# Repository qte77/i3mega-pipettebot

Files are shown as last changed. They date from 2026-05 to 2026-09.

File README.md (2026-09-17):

# i3mega-pipettebot

> Turn a cheap consumer 3D printer into a sub-$150 disposable-tip pipetting
> robot driven by a **DLAB dPette** electronic pipette and Python.

Reference build is **dpette+i3** (Anycubic i3 Mega + DLAB dPette+);
**Geeetech A30 (Smartto firmware)** is also a supported gantry via the
same `pipettebot` library — discovery picks the firmware family from
`M115` and the `safe_home` dispatcher routes Marlin → plain `G28` and
Smartto → polled-Z descent (firmware `G28 Z` is broken on stock A30
builds; see [ADR 0004](docs/adr/0004-printer-firmware-policy-and-safe-home.md)
and the [bring-up notes](docs/research/gantry-firmware-alternatives.md)).
Firmware stays unmodified on every supported platform; the print head
and PCB are physically removed from the carriage and the chassis is
repurposed as a 3-axis motion platform with the dPette mounted on the
bare carriage (see [`docs/3d-parts.md`](docs/3d-parts.md)). The pipette
is driven over a separate USB-serial link via
[`dpette-usb-driver`](https://github.com/Lambda-Biolab/dpette-usb-driver),
and used-tips bin pickup is delegated to an optional companion SO-101
arm via [`so101-biolab-automation`](https://github.com/qte77/so101-biolab-automation).
The library is also pipette-agnostic via the `_Pipette` Protocol.

**Write-up:** [A $150 Pipetting Robot from a Stock 3D Printer](https://qte77.github.io/pipettebot-sub-150-pipetting-robot/) — the full build story. This gantry is also the *motion layer* of a larger [self-driving-lab agent loop](https://qte77.github.io/open-self-driving-lab-agent-loop/).

<details>
<summary>dpette+i3 in action (animated GIF)</summary>
<p align="center">
  dpette+i3 (i3 Mega) pipetting robot in action
</p>
</details>








## Why this matters

A pipetting robot you can build for the price of a 3D printer, with a
disposable-tip workflow and Python control. See
[docs/UserStory.md](docs/UserStory.md) for the target personas,
end-to-end workflows, and what is explicitly out of scope.

| Solution | Cost | Tips | API control |
|---|---|---|---|
| **i3 Mega (used) + dPette (new) + this repo** | **~$150** | Disposable  | Python |
| **A30 (used) + dPette (new) + this repo** | **~$200** | Disposable  | Python |
| [Science Jubilee][sj] + OT-2 pipette | ~$900+ build  | Disposable  | Python |
| [Opentrons OT-2][ot2] | from $15,950  | Disposable  | Python |

[sj]: https://science-jubilee.readthedocs.io/en/latest/
[ot2]: https://opentrons.com/products/ot-2-robot

Prices: Opentrons is the vendor list; Jubilee is a community build estimate
anchored at the [Science Jubilee project][sj] ([OT-2 pipette toolhead][sj-pipette]).

[sj-pipette]: https://science-jubilee.readthedocs.io/en/latest/building/pipette_tool.html

## Quickstart

Requires [`uv`](https://docs.astral.sh/uv/).

```bash
# Install uv once (if you don't have it):
# curl -LsSf https://astral.sh/uv/install.sh | sh

git clone https://github.com/qte77/i3mega-pipettebot.git
cd i3mega-pipettebot
make setup_dev
make test
```

`make setup_dev` runs `uv sync --extra dev`; `make test` runs the
mocked-serial test suite (no hardware required). `make help` lists every
recipe grouped by section.

## Run the demo (requires hardware)

Two separate guides cover the physical/electrical setup and the
well-origin calibration before you run the demo:

- [`docs/hardware.md`](docs/hardware.md) — cabling, port discovery (CH340 vs CP2102), Marlin firmware sanity check
- [`docs/calibration.md`](docs/calibration.md) — finding well A1 with `M114`, the 9 mm pitch check, where to set the constants

After hookup, sanity-check ports + firmware **before any motion**:

```bash
uv run tools/preflight.py
```

This reads `M115` from Marlin and the EEPROM packet from the dPette;
no motion is sent. Preflight passes when **either** device is found —
the gantry and the pipette are exercised independently.

To chain discovery directly into the next command, use `--export`:

```bash
eval "$(uv run python tools/preflight.py --export)" \
  && uv run python examples/showcase_v0_i3_pipette_sim.py
```

Then the demo. Hardware examples drive the gantry (and, for the
canonical end-to-end demo, also the dPette) and tee the Marlin stream
to disk for replay/SD use. **Precondition for all full-plate demos:
REMOVE TIPS from the dPette before running.** Phase 1 issues
`G28 X Y Z` — Z homes to its calibrated tip-on-deck zero, which would
drag any mounted tip into the deck.

```bash
# back-well ↔ front-well pipetting cycle (older two-well demo, simulated)
uv run examples/showcase_v0_i3_pipette_sim.py

# Full 96-well plate fill, gantry-only (aspirate/dispense simulated via
# Z dives). Useful for gantry/cabling bring-up without the dPette.
uv run examples/showcase_v0_i3_full_plate.py

# Canonical end-to-end demo — same gantry tour with REAL dPette
# aspirate/dispense (B3 SUCK at reservoir, B3 BLOW at each SBS column).
# Needs both PRINTER_PORT and PIPETTE_PORT set.
uv run examples/showcase_v0_i3_full_pipettebot.py

# dPette-only bench test — 12 aspirate/dispense cycles, no gantry. Use
# to measure real B3 motor timing. Run with tip in air or over waste.
uv run examples/showcase_v0_i3_full_dpette_cycles.py

# Every showcase (column/dpette-cycles/rows) accepts a TOML experiment
# profile via PIPETTE_PROFILE — drives the cycle count, per-cycle volumes,
# and any pre-mixed reservoir gradient notes. Profile length overrides the
# script's default (NUM_COLUMNS / NUM_CYCLES). See
# `examples/experiment_profiles/` for samples
# (calibration_curve_demo.toml, gradient_reservoir_demo.toml).
PIPETTE_PROFILE=examples/experiment_profiles/calibration_curve_demo.toml \
  uv run examples/showcase_v0_i3_full_dpette_cycles.py
PIPETTE_PORT=/dev/ttyUSB1 \
  PIPETTE_PROFILE=examples/experiment_profiles/calibration_curve_demo.toml \
  uv run examples/showcase_v0_i3_full_pipettebot_rows.py

# Every gantry-using example also accepts MOTION_PROFILE to dial gantry
# accel/jerk between slow / mid / fast (or off to skip the install).
# Default is mid (liquid-handling friendly). See
# `src/pipettebot/motion_profile.py` for the bundled values + semantics.
MOTION_PROFILE=fast NUM_CYCLES=1 \
  uv run examples/showcase_v0_i3_full_pipettebot_rows.py

# Home — full `G28` to (X=0, Y=0, Z=0). Bootstrap installs the same
# liquid-handling motion profile (M203/M201/M204/M205) that every
# showcase_v0_*.py installs, so chaining a home before a tour leaves a
# known motion state. No partial-axis shortcuts.
uv run examples/home_G28_fast_i3.py
```

### Geeetech A30 (Smartto firmware)

The same toolchain drives an A30 — discovery picks `smartto` from `M115`,
the `safe_home` library routes around firmware-broken `G28 Z` via a
polled-Z descent against the working inductive sensor, and a parallel
showcase exercises the deck:

```bash
# Z home only — polled descent finds the sensor, declares G92 Z0.
uv run examples/home_safe_a30.py

# End-to-end liquid-handling demo — discovery, home, N cycles with
# split-feedrate dives, post-cycle re-home, park at (0, 0, 0). Runs
# in GANTRY-ONLY mode when PIPETTE_PORT is unset (motion executes for
# real; aspirate/dispense are log-only stubs).
uv run examples/showcase_v0_a30_liquid_handling.py
```

See [`docs/research/gantry-firmware-alternatives.md`](docs/research/gantry-firmware-alternatives.md)
for the A30 bring-up notes and [ADR 0004](docs/adr/0004-printer-firmware-policy-and-safe-home.md)
for the `safe_home` design.

The full-plate tour's deck layout (slot positions, motion constants,
tour sequence) is the canonical spec — see
[`docs/deck-layout.md`](docs/deck-layout.md).

### Hardware diagnostics (`tools/`)

For headless-gantry bring-up, debugging, and post-removal sanity checks:

| Tool | Purpose |
|---|---|
| `tools/preflight.py` | Port discovery + Marlin/dPette firmware probe. |
| `tools/diagnose_axis.py` | Per-axis (`AXIS=X\|Y\|Z`) stepped motion under operator confirmation. Reports `M119` first, never homes. |
| `tools/marlin_repl.py` | Interactive G-code REPL with built-in command cheat-sheet (`?`). For ad-hoc `M119`, `M999`, `M114`, `M503`, etc. |

See [`docs/marlin-commands.md`](docs/marlin-commands.md) for the full
G/M-code reference and i3 Mega coordinate orientation.

### CAD + slicer pipeline (`tools/cad/`, `tools/slicer/`)

build123d CAD scripts for printable parts — tip rack, plate holder, dPette
cradles, tip ejector, **i3 carriage dPette+ mount**. `make render_parts`
generates STL+SVG from `tools/cad/parts.json`; `make check_prints` slices
via OrcaSlicer (preferred) or PrusaSlicer (fallback). Hardware measurements
are consolidated in `tools/cad/measurements.py`. See
[`docs/3d-parts.md`](docs/3d-parts.md) for the CAD pipeline design
rationale and payload / Z-envelope math.

Expected behavior: home → bed sweeps to back well → 5 cm Z plunger
stroke → bed sweeps to front well → another stroke → home.

## Architecture

```text
examples/showcase_v0_i3_pipette_sim.py     examples/showcase_v0_a30_liquid_handling.py
        │                                                │
        ▼                                                ▼
raw serial @ 250000 baud                   pipettebot.gantry + safe_home dispatcher
        │                                                │
        ▼                                                ▼
/dev/ttyUSB*  (Marlin / AI3M)              /dev/ttyUSB*  (Smartto / A30 @ 115200)
        │
        └─ tee G-code stream ──► OUTPUT_GCODE file (replay / SD)
```

Both printer families share `tools/preflight.py --export` for discovery
(`PRINTER_PORT` is the single env var) and the same library. Firmware
family is identified by `pipettebot.devices.discover()`, and
`safe_home` dispatches per-family: plain `G28` on Marlin, polled-Z
descent on Smartto/A30 (firmware `G28 Z` is broken on stock Smartto).
See [ADR 0004](docs/adr/0004-printer-firmware-policy-and-safe-home.md).

The dPette is wired in via `dpette.DPetteDriver`.
`showcase_v0_i3_full_pipettebot.py` runs the full plate fill end-to-end —
gantry transit + real B3 SUCK/BLOW at the bottom of each dive.
`showcase_v0_i3_full_plate.py` keeps the gantry-only path (plunger
simulated via Z) for bring-up without the pipette.
`showcase_v0_a30_liquid_handling.py` is the A30 counterpart with the
polled-Z home + split-feedrate dives; runs in gantry-only mode when
`PIPETTE_PORT` is unset.

Seven library modules under `src/pipettebot/`: `gantry.py` (G-code
wrapper + `send`/`query`/`flush_input` public surface), `bot.py`
(`PipetteBot` composer), `devices.py` (firmware discovery via M115,
per-family `FirmwarePolicy`, `safe_home` dispatcher),
`experiment_profile.py` (TOML experiment-profile loader; see
[`examples/experiment_profiles/`](examples/experiment_profiles/)),
`motion_profile.py` (bundled SLOW/MID/FAST gantry-tuning factors at
3x ratio; `MOTION_PROFILE` env selects), `cli_profile.py` (shared
`PIPETTE_PROFILE` / `PIPETTE_VOLUME_UL` env resolution), and
`__init__.py` (re-exports). No deck library, no safety limits, no
calibration yet — the caller passes raw `(x, y, z)`.

## Development

| Recipe | What it runs |
|---|---|
| `make setup_uv` | install uv (idempotent — skips if already on PATH) |
| `make setup_prod` | `uv sync` (runtime deps only — pyserial + dpette) |
| `make setup_dev` | `uv sync --extra dev` (runtime + ruff/mypy/pytest/complexipy/hypothesis) |
| `make setup_cad` | `uv sync --extra cad` (build123d) |
| `make setup_slicer` | probe for OrcaSlicer (preferred) or PrusaSlicer (fallback) |
| `make setup_prusa_presets` | extract MK4 Input Shaper presets into `~/.config/PrusaSlicer/` (enables `make slice` to reference them by name) |
| `make setup_all` | `setup_dev` + `setup_cad` + best-effort slicer/diagramforge |
| `make validate` | `ruff format --check` + `ruff check` + `mypy --strict` + `pytest -m "not hardware"` |
| `make quick_validate` | `ruff check` + `mypy` only (no tests) |
| `make lint` | `ruff check` + `mypy --strict` |
| `make lint_fix` | `ruff format` + `ruff check --fix` |
| `make test` | `pytest -v` (hardware tests excluded via `pyproject.toml`) |
| `make test_bats` | bats tests for Makefile recipe wiring (`tests/bats/*.bats`) |
| `make check_complexity` | `complexipy src/pipettebot/` (max 15) |
| `make check_links` | `lychee` against the repo (config in `.lychee.toml`) |
| `make check_docs` | `markdownlint-cli2 "**/*.md"` |
| `make check_deploy` | shellcheck + bats + `systemd-analyze verify` for `tools/deploy/` (best-effort `udevadm`) |
| `make render_parts` | build123d → STL/STEP/SVG (driven by `tools/cad/parts.json`) |
| `make check_prints` | headless slice via `tools/slicer/validate.py --all` |
| `make render_all` | `render_parts` + `check_prints` (full CAD-to-slicer gate) |
| `make slice PART=<name>` | PrusaSlicer STL → tracked `hardware/bgcode/<area>/<part>.bgcode` via named Input Shaper presets (run `setup_prusa_presets` first) |
| `make dev_diagram` | run diagramforge's dev server for architecture-diagram editing (run `setup_diagramforge` first) |

Recipes prefer the local `.venv/bin/<tool>` binary if installed, else fall
back to `uv run`. On read-only hosts where `uv run` can't write to
`~/.cache/uv`, run `make setup_dev` first (which materialises the venv)
or set `UV_CACHE_DIR=$TMPDIR/uv-cache`.

The `setup_*` recipes pass `--inexact` to `uv sync` so they are
**additive**: running `setup_dev` after `setup_cad` keeps `build123d`
installed (and vice versa). Without `--inexact`, `uv sync` is exact
and uninstalls anything outside the requested extras.

Hardware tests are gated by `@pytest.mark.hardware`:

```bash
uv run pytest -m hardware
```

## Architecture decision: why PC-as-host (no firmware mods)

Marlin runs unmodified. Pipetting cycles are slow (seconds per move,
seconds per aspirate); USB-serial round-trip latency (~20–50 ms) is
inconsequential. Firmware integration (Stage 1 config patch, Stage 2
UART tap to dPette) is deliberately **out of scope** for the current
PC-as-host architecture. See [ADR 0005](docs/adr/0005-pc-as-host.md)
for the full Stage 0–2c breakdown and what would trigger moving past
Stage 0.

## Related repositories

- [Lambda-Biolab/dpette-usb-driver](https://github.com/Lambda-Biolab/dpette-usb-driver) — pipette serial driver (imported as `dpette`); reference pipette for the **dpette+i3** build.
- [qte77/so101-biolab-automation](https://github.com/qte77/so101-biolab-automation) — dual SO-101 arm controller; optional companion that retrieves the used-tips bin after the i3 homes (issue #120).
- [xg590/Learn_dPettePlus](https://github.com/xg590/Learn_dPettePlus) — original reverse-engineering of the dPette+ serial protocol (source of the official Chinese protocol document); intellectual lineage for `dpette-usb-driver`.

## Documentation

- [docs/UserStory.md](docs/UserStory.md) — user personas, target workflows, scope and acceptance criteria
- [docs/roadmap.md](docs/roadmap.md) — forward-looking work (near-term, Stage 1+ firmware, deferred API tiers, anti-roadmap)
- [docs/hardware.md](docs/hardware.md) — i3 Mega + dPette wiring, port discovery, firmware sanity check, dPette+ specs
- [docs/calibration.md](docs/calibration.md) — well-A1 origin procedure, 9 mm pitch check
- [docs/deck-layout.md](docs/deck-layout.md) — deck slot extents, motion constants, four-phase tour sequence (canonical spec for `showcase_v0_i3_full_plate.py`)
- [docs/marlin-commands.md](docs/marlin-commands.md) — Marlin G/M-code reference + i3 Mega coordinate orientation
- [docs/3d-parts.md](docs/3d-parts.md) — CAD pipeline design rationale, payload + Z envelope math, SBS labware reference
- [docs/sbc-deployment.md](docs/sbc-deployment.md) — Path 2 (Single-Board Computer on-printer) deployment
- [docs/research/gantry-firmware-alternatives.md](docs/research/gantry-firmware-alternatives.md) — A30 / Smartto bring-up notes (firmware-broken `G28 Z`, polled-Z descent recipe)
- [docs/research/aspirate-monitoring.md](docs/research/aspirate-monitoring.md) — aspirate verification technologies (Hamilton MAD / TADM survey, dPette+ reuse verdict)
- [docs/research/tip-disposal-belt-module.md](docs/research/tip-disposal-belt-module.md) — used-tip disposal mechanisms (conveyor-belt printer landscape, standalone belt module BOM)
- [docs/research/alternative-pipettes.md](docs/research/alternative-pipettes.md) — candidate pipettes for the `_Pipette` Protocol (dPette+ reference, multichannel, Opentrons GEN2, ac-rad Digital Pipette)
- [docs/adr/](docs/adr/) — architectural decision records
- [AGENTS.md](AGENTS.md) — agent rules, decision framework, architecture
- [AGENT_LEARNINGS.md](AGENT_LEARNINGS.md) — gotchas as we discover them
- [CONTRIBUTING.md](CONTRIBUTING.md) — dev workflow
- [CHANGELOG.md](CHANGELOG.md) — version history

## License

Apache-2.0 — see [LICENSE](LICENSE) and [NOTICE](NOTICE).

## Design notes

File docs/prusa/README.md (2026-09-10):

---
title: "Prusa MK4 + PrusaSlicer workflow notes"
status: "ACTIVE"
updated: "2026-05-17"
---

Workflow notes and CLI quirks discovered while slicing this repo's
labware (deck plate + dpette parts) on a Prusa MK4 with PrusaSlicer
2.9.4. Recommended path for actual prints is the **GUI**, not the
CLI — see "When to use the CLI" below.

## Quick reference

| What | Where |
|---|---|
| Bed dimensions (MK4) | 250 mm (X) × 220 mm (Y) × 220 mm (Z) |
| System preset bundle | `/usr/share/PrusaSlicer/profiles/PrusaResearch.ini` (1.5 MB, 36 MK4 variants) |
| User config dir | `~/.config/PrusaSlicer/` (presets dirs empty by default — GUI reads system bundle) |
| Repo profiles | `tools/slicer/profiles/*.ini` (minimal; documentation + reference only) |
| Repo STL output | `hardware/stl/<area>/<part>.stl` |
| Repo STEP output | `hardware/step/<area>/<part>.step` |
| Network upload to MK4 | PrusaLink HTTP over RJ45 (`tools/slicer/upload_to_prusalink.py`) |
| Offline upload to MK4 | USB-A thumb drive on the printer front |
| Binary G-code (`.bgcode`) | Smaller, MK4 native — use `--binary-gcode` |

## PrusaSlicer 2.9.4 CLI quirks (verified)

These bit us during this work — document so future-us doesn't
re-debug. Tested with `prusa-slicer 2.9.4 (Fedora build)`.

### Quirk 1 — `.ini` profiles don't reliably load via `--load`

The minimal profiles under `tools/slicer/profiles/*.ini` set keys
like `bed_shape`, `binary_gcode`, `gcode_flavor`, `thumbnails`,
`layer_height`, `fill_density`, `temperature`, and the per-feature
speed keys (`perimeter_speed`, `infill_speed`, ...).

**Behavior**: when invoked as `prusa-slicer --load profile.ini …`,
PrusaSlicer silently falls back to **defaults** for most of these
keys. The slicer doesn't error or warn; the output just doesn't
match the profile.

**Confirmed-loaded** via `--load`:

- `nozzle_diameter` (sometimes)
- `printer_model` (sometimes)
- A few filament keys

**Confirmed-NOT-loaded** via `--load`:

- `bed_shape` — falls back to 200 × 200 default
- `binary_gcode` — output stays plain ASCII G-code
- `gcode_flavor` — no MK4 hints in output
- `thumbnails` — no thumbnails block, no preview on MK4 screen
- `layer_height`, `fill_density`, `brim_width` — default values used
- All `*_speed` keys — defaults used (60 / 80 / 130 mm/s)
- `temperature` (filament) — defaults used

**Workaround**: pass every required key as an **explicit CLI flag**.
A working ultra-draft invocation:

```bash
prusa-slicer --binary-gcode --export-gcode \
  --bed-shape 0x0,250x0,250x220,0x220 \
  --gcode-flavor marlinfirmware \
  --thumbnails 220x124/PNG,16x16/PNG \
  --printer-model MK4 \
  --nozzle-diameter 0.4 \
  --layer-height 0.3 --first-layer-height 0.2 \
  --perimeters 2 --fill-density 10% \
  --brim-width 5 \
  --temperature 230 --bed-temperature 55 \
  --filament-type PLA --extrusion-multiplier 0.7 \
  --output OUT.bgcode INPUT.stl
```

### Quirk 2 — preset-by-name (`--printer-profile NAME`) fails

The system preset bundle at
`/usr/share/PrusaSlicer/profiles/PrusaResearch.ini` contains 36 MK4
variants (`Original Prusa MK4 0.4 nozzle`, `… Input Shaper 0.4 nozzle`,
etc.) and hundreds of print/filament presets, but the CLI doesn't
find them by name:

```bash
prusa-slicer --printer-profile "Original Prusa MK4 Input Shaper 0.4 nozzle" \
  --print-profile "0.20mm SPEED @MK4IS 0.4" \
  --material-profile "Prusa PLA" …
# Error: Printer profile '…' wasn't found.
```

Pointing at the system bundle with `--datadir
/usr/share/PrusaSlicer` also fails:

```text
Error: Configuration wasn't found. Check your 'datadir' value.
```

`--datadir` expects a USER data dir shape (`print/`, `printer/`,
`filament/` subdirs containing individual preset `.ini` files), not
the system vendor bundle.

**Workaround**: open the file in the GUI once, save the relevant
preset to the user data dir, then `--datadir ~/.config/PrusaSlicer`
will find it. Or just stick with explicit CLI flags.

### Quirk 3 — "objects outside print volume" exits 0

If the input STL's bounding box extends past the bed, PrusaSlicer
prints `All objects are outside of the print volume.` to stdout and
**exits with code 0**. No G-code is written. `make check_prints` /
`tools/slicer/validate.py` doesn't catch this because the gate
keys on exit code + a hand-picked overhang keyword list.

**Workaround**: pre-translate STLs so `min_xy >= 0` before slicing.
We do this for the deck-plate assembly STL (origin at well-plate
left-front means literal coords go negative). A small build123d
helper:

```python
from build123d import Pos, import_stl, export_stl
mesh = import_stl('hardware/stl/labware/deck_plate_assembly.stl')
shifted = Pos(10, -12.5, 0) * mesh   # move bbox min to (0,0,0)
export_stl(shifted, '/tmp/deck_assembly_for_print.stl')
```

**Pending validate.py fix**: add `"outside of the print volume"`
and `"could not be sliced"` to `OVERHANG_KEYWORDS`, and require an
output file to exist before declaring PASS.

### Quirk 4 — `--center` / `--align-xy` don't reposition reliably

The CLI exposes `--center X,Y` and `--align-xy X,Y` transform
options, but in 2.9.4 they did NOT reposition off-bed STLs to fit
in our tests. Pre-translation (Quirk 3) is the only reliable path.

### Quirk 5 — Input Shaper preset must be in user data dir

The MK4 firmware refuses bgcode that wasn't sliced for Input Shaper
("gcode not sliced for input shaping"). The IS-aware preset
`Original Prusa MK4 Input Shaper 0.4 nozzle` lives in the system
bundle at `/usr/share/PrusaSlicer/profiles/PrusaResearch.ini`, but
neither `--printer-profile NAME` nor `--load <bundle>` can select
it directly from there.

The CLI only finds presets in `~/.config/PrusaSlicer/{printer,print,
filament}/`. PrusaSlicer GUI populates this on first run; the CLI
does not.

**Workaround**: extract the resolved preset (walking the `inherits =
*commonMK4*` chain) and write it as a flat `.ini` to the user data
dir. After that, `--printer-profile "Original Prusa MK4 Input
Shaper 0.4 nozzle"` works and emits the correct M593 + IS-tuned
machine_max_acceleration_* / feedrate / jerk values.

Minimal Python extractor:

```python
import re
from pathlib import Path
BUNDLE = '/usr/share/PrusaSlicer/profiles/PrusaResearch.ini'
USER = Path.home() / '.config' / 'PrusaSlicer'

def parse(p):
    sec, name, buf = {}, None, []
    for line in open(p):
        m = re.match(r'^\[([^\]]+)\]\s*$', line)
        if m:
            if name: sec[name] = buf
            name, buf = m.group(1), []
        else: buf.append(line)
    if name: sec[name] = buf
    return sec

def kv(lines):
    d = {}
    for ln in lines:
        s = ln.strip()
        if s and not s.startswith('#') and '=' in s:
            k, v = s.split('=', 1); d[k.strip()] = v.strip()
    return d

def resolve(sec, full, visited=None):
    visited = visited or set()
    if full in visited: return {}
    visited.add(full)
    body = kv(sec[full])
    inh = body.pop('inherits', None)
    if inh:
        kind = full.split(':',1)[0]
        for parent in re.split(r'[;,]', inh):
            p = parent.strip().strip('"\'')
            if p:
                for k, v in resolve(sec, f'{kind}:{p}', visited).items():
                    body.setdefault(k, v)
    return body

s = parse(BUNDLE)
for kind, name in [
    ('printer', 'Original Prusa MK4 Input Shaper 0.4 nozzle'),
    ('print',   '0.20mm SPEED @MK4IS 0.4'),
    ('filament','Prusa PLA'),
]:
    body = resolve(s, f'{kind}:{name}')
    d = USER / kind; d.mkdir(parents=True, exist_ok=True)
    with open(d / f'{name}.ini', 'w') as f:
        for k, v in body.items(): f.write(f'{k} = {v}\n')
    print(f'wrote {kind}/{name}.ini ({len(body)} keys)')
```

Run once on the workstation (outside any sandbox), then CLI slice
with:

```bash
prusa-slicer --binary-gcode --export-gcode \
  --printer-profile "Original Prusa MK4 Input Shaper 0.4 nozzle" \
  --print-profile   "0.20mm SPEED @MK4IS 0.4" \
  --material-profile "Prusa PLA" \
  --output OUT.bgcode INPUT.stl
```

**Packaged as `make setup_prusa_presets`** (`tools/slicer/resolve_presets.py`,
issue #129). One caveat found while wrapping it: this repo's installed
`prusa-slicer` (2.7.2, in the devcontainer used to verify this) doesn't
recognize `--printer-profile` / `--print-profile` / `--material-profile`
at all (`Unknown option`, confirmed via `--help-fff`) — those flags were
confirmed only against 2.9.4 above; whether 2.9.4 CLI behavior differs
is not verified here. `--load <resolved-preset-file>` (one flag per
file) is the version-portable equivalent, and it isn't just accepted
and silently defaulted (the failure mode Quirk 1 describes for this
repo's own *minimal* `tools/slicer/profiles/*.ini`): a real, non-mocked
`--load`×3 slice in that environment produced output whose embedded
metadata carried the resolved preset's own values verbatim
(`printer_model=MK4IS`, `layer_height=0.2`, `temperature=210`,
`fill_density=15%`), where a `--load`-free control slice of the same
STL showed only PrusaSlicer's generic defaults
(`printer_model=<empty>`, `layer_height=0.3`, 200×200 bed). The
resolved `binary_gcode` key alone flipped the output to real binary
`GCDE` bgcode with no `--binary-gcode` flag passed. `make slice`
(`tools/slicer/slice.py`, issue #128) uses `--load` against the files
this recipe writes, so the CLI surface
(`--printer-preset`/`--print-preset`/`--filament-preset`) still reads
as name-based even though the underlying invocation differs from the
one shown above.

### Quirk 6 — `start_gcode` empty by default → printer doesn't auto-heat

Without a loaded preset, PrusaSlicer's `start_gcode` field is empty.
A bgcode sliced via `--load <minimal.ini>` will not contain `M140`
/ `M190` / `M104` / `M109` / `G28` commands, so when the printer
starts the file it does **not** heat the bed or nozzle automatically
— the operator has to set temps and home manually on the printer
screen before the print proceeds.

PrusaSlicer auto-emits a single `M104 S<default>` if it detects no
M104 in the start gcode, but uses the DEFAULT first-layer
temperature (200 °C), not the one you passed via `--temperature`.
There's no auto-emit of M140/M190/G28.

**Workaround**: pass an explicit `--start-gcode` (and `--end-gcode`)
with proper sequencing. Use ANSI-C shell quoting (`$'...\n...'`) so
newlines reach PrusaSlicer literally — `"...\n..."` in plain double
quotes ends up as a single comment line containing literal `\n`
characters, and PrusaSlicer auto-emits its own `M104 S200` *before*
the would-be custom block (which now looks like a comment to it).

Working invocation:

```bash
prusa-slicer --binary-gcode --export-gcode \
  --bed-shape 0x0,250x0,250x220,0x220 \
  --gcode-flavor marlinfirmware --printer-model MK4 \
  --nozzle-diameter 0.4 --layer-height 0.3 --first-layer-height 0.2 \
  --perimeters 2 --fill-density 10% --brim-width 5 \
  --temperature 230 --first-layer-temperature 230 \
  --bed-temperature 55 --first-layer-bed-temperature 55 \
  --filament-type PLA --extrusion-multiplier 0.7 \
  --start-gcode $'M140 S[first_layer_bed_temperature]\nM104 S[first_layer_temperature]\nG28\nM190 S[first_layer_bed_temperature]\nM109 S[first_layer_temperature]\nG1 Z5 F600' \
  --end-gcode   $'G1 Z+10 F300\nG28 X0 Y0\nM104 S0\nM140 S0\nM84' \
  --output OUT.bgcode INPUT.stl
```

The sequence inside the start gcode matters:

1. `M140` (no-wait set bed temp) — bed starts heating
2. `M104` (no-wait set nozzle temp) — nozzle starts heating in parallel
3. `G28` — home while both heat up
4. `M190` (wait for bed) — block until bed is hot
5. `M109` (wait for nozzle) — block until nozzle is hot
6. `G1 Z5 F600` — lift nozzle before extruding so the heated nozzle
   doesn't drag on the bed

PrusaSlicer's placeholder substitution (`[first_layer_temperature]`
etc.) only works if the line is parsed as G-code, which requires
real newlines.

**Related**: `--first-layer-temperature` / `--first-layer-bed-temperature`
are SEPARATE from `--temperature` / `--bed-temperature`. The
auto-emit and the `[first_layer_temperature]` placeholder both use
the first-layer values. Set both pairs to the same value unless you
deliberately want first-layer to differ.

### Quirk 7 — speeds get overridden by cooling logic

Even when `--perimeter-speed 30` is accepted, PrusaSlicer's cooling
logic adjusts per-layer speed based on `cooling`,
`fan-below-layer-time`, and `slowdown-below-layer-time`. The
embedded G-code header shows the requested speed; the actual
movements run slower if layers are estimated short.

For LW-PLA on a 219 × 219 mm footprint at 0.3 mm layer, expect
2-3× slowdown vs the configured perimeter_speed.

## When to use the CLI vs the GUI

- **GUI (preferred for actual prints)**: handles presets, thumbnails,
  arrangement, Input Shaper variants, LW-PLA fine-tuning correctly.
- **CLI (good for batch validation / gates)**: minimum-viable slice
  for `make check_prints`. Don't trust CLI G-code output for actual
  printing without GUI verification.

## Cheat sheet: actual print workflow

1. **Slice in GUI**: open PrusaSlicer GUI, pick "Original Prusa MK4 Input
   Shaper 0.4 nozzle" + a Prusa print profile (e.g. "0.20mm SPEED
   @MK4IS 0.4" for production, "0.28mm DRAFT @MK4IS HF0.4" for draft
   if HF nozzle).
2. **Import STL**: `hardware/stl/labware/deck_plate_<half|assembly>.stl`.
3. **Verify auto-arrangement** puts the part on the bed (GUI does this
   automatically — CLI does not).
4. **Tune for LW-PLA** if loaded: extrusion multiplier ≈ 0.7,
   temperature ≈ 230 °C, perimeter speed 25-30 mm/s.
5. **Slice + save** as `.bgcode` (Configuration → Preferences → Other
   → "Use binary G-code…" must be enabled).
6. **Upload via PrusaLink** (RJ45) or USB thumb drive.

## Estimated print times (MK4 + LW-PLA, this deck plate)

With through-hole cutouts under each labware slot (current design):

| Settings | Time | Filament |
|---|---|---|
| LW-PLA prototype (no cutouts, old) | 10 h 54 m | 25.4 m |
| LW-PLA ultra-draft (with cutouts) | 1 h 40 m | 4.3 m |
| LW-PLA prototype (with cutouts, est.) | ~3 h | ~6 m |

Cutouts saved ~85% of print time. The deck became a window-frame
holding lip walls around openings — labware drops to the heated bed.

## Pending CLI improvements (tracked separately)

- `tools/slicer/validate.py`: add `"outside of the print volume"` and
  `"could not be sliced"` to warning keywords; require output file
  to exist before PASS.
- `_build_slicer_cmd`: forward `.ini` keys as explicit CLI flags so
  the gate actually validates against the configured profile.
- `make slice` recipe (**done**, issue #128): produces a tracked
  `.bgcode` artifact under `hardware/bgcode/<area>/<part>.bgcode` — see
  Quirk 5 above for the actual (`--load`-based) invocation it uses.

## References

- Prusa MK4 spec: <https://www.prusa3d.com/product/original-prusa-mk4-2/>
- PrusaSlicer 2.9 release notes: <https://github.com/prusa3d/PrusaSlicer/releases>
- PrusaResearch bundle (system): `/usr/share/PrusaSlicer/profiles/PrusaResearch.ini`
- Binary G-code format (bgcode): <https://github.com/prusa3d/libbgcode>
- Repo profiles: [`tools/slicer/profiles/`](../../tools/slicer/profiles/)
- Slicer validator: [`tools/slicer/validate.py`](../../tools/slicer/validate.py)

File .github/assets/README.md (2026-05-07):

# Asset slots

README hero and showcase media live here. These are **placeholders** —
generate real images post-scaffold. The repo intentionally has **no
social-preview asset**; GitHub's default repo card is used instead.

| Slot | Path | Dimensions | Used by |
|---|---|---|---|
| README hero | `hero.png` | ~1600×800 | `README.md` top-of-page |
| Showcase loop | `showcase.gif` | ~800×450 | Linked from README "Quickstart"  |

Mirrors the asset pattern used by `CellPlateVision/.github/` and the
org-level `lambda/.github/assets/`.

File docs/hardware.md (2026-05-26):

---
title: "Hardware setup"
status: "DRAFT"
updated: "2026-05-17"
owner: "qte77"
---

This guide covers the **physical and electrical setup** of an Anycubic
i3 Mega chassis (stripped to a 3-axis motion platform — see "Workspace
constraints" below) and a DLAB dPette electronic pipette so the v0 demo
(`examples/showcase_v0_i3_pipette_sim.py`) can run end-to-end. Software
install is covered in the [README](../README.md) and contributor setup
in [CONTRIBUTING](../CONTRIBUTING.md).

## Topology

Two USB cables, one to the printer and one to the pipette:

```text
PC ──USB-B──► Anycubic i3 Mega   (Trigorilla, ATmega2560, Marlin) /dev/tty?  250000 8N1
PC ──CP2102──► DLAB dPette                                         /dev/tty?  9600 8N1
```

The PC is the orchestrator. Marlin executes G-code; the dPette executes
6-byte serial commands via [`dpette-usb-driver`](https://github.com/Lambda-Biolab/dpette-usb-driver). They never talk to each
other directly in v0.

## Anycubic i3 Mega

| Item | Value |
|---|---|
| Mainboard | Trigorilla 0.0.4 (ATmega2560 + A4988 drivers, stock) |
| Firmware | Anycubic stock Marlin 1.4.x **or** upstream Marlin 2.x **or** community MARLIN-AI3M |
| USB bridge chip | CH340 *(older boards)* **or** CP2102N *(newer batches and many MARLIN-AI3M-flashed units)* |
| VID:PID | `1a86:7523` (CH340) **or** `10c4:ea60` (CP2102N) |
| Baud | 250000 8N1 (Anycubic stock and MARLIN-AI3M); some custom builds use 115200 |
| Connector | USB-B on the LCD/board housing |

> The dPette also uses a Silicon Labs CP210x at `10c4:ea60` (see below). On
> a CP2102N-equipped i3 Mega the two devices share VID:PID, so you cannot
> tell them apart by descriptor alone — fall back on the chip's serial
> number, or use the `M115` probe in [Distinguishing the two ports](#distinguishing-the-two-ports).

We use **stock Marlin without modifications** in v0. The G-code surface we
need is small: `G28`, `G1`, `M114`, `M115`, `M400`. Both 1.4.x and 2.x
support all of these.

For project provenance, fork lineage, license posture, and OSS
alternatives to the Marlin/slicer stack, see
[`research-oss-toolchain.md`](research-oss-toolchain.md).

### Confirming the printer port

After plugging in the printer, find its `/dev/tty*` device:

```bash
# Linux — newest CH340 enumeration shows in dmesg
dmesg | tail -20 | grep -i ch34
# Expected: usb 1-1: ch341-uart converter now attached to ttyUSB0

# Or query udev directly
udevadm info /dev/ttyUSB0 | grep -E 'ID_VENDOR_ID|ID_MODEL_ID|ID_VENDOR'
# Expected: ID_VENDOR_ID=1a86, ID_MODEL_ID=7523
```

```bash
# macOS
system_profiler SPUSBDataType | grep -A8 -i 'CH34\|wch'
ls /dev/cu.wchusbserial* /dev/cu.usbserial-* 2>/dev/null
```

If the printer enumerates differently on your build (e.g. SKR/Spider
upgrade swapping CH340 for CP2102 or FTDI), substitute the matching
VID:PID in the table below.

### Marlin firmware sanity check

Once you have the port, send `M115` and read the firmware string. The
[`tools/preflight.py`](../tools/preflight.py) script does this for
you; manually it looks like:

```bash
# Replace /dev/ttyUSB0 with your printer port
stty -F /dev/ttyUSB0 250000 raw
printf 'M115\n' > /dev/ttyUSB0 && timeout 2 cat /dev/ttyUSB0
# Expected first line: FIRMWARE_NAME:Marlin 1.1.X (Anycubic Mega ...) ...
```

## DLAB dPette / dPette+

The pipette's USB cable terminates in a Silicon Labs CP2102 USB-UART
bridge. Full protocol details — including the standby/connectable
button-press quirk and the 6-byte packet format — are in
[`dpette-usb-driver/docs/HARDWARE.md`](https://github.com/Lambda-Biolab/dpette-usb-driver/blob/main/docs/HARDWARE.md).

### USB connection

| Item | Value |
|---|---|
| USB bridge chip | CP2102 |
| VID:PID | `10c4:ea60` |
| Baud | 9600 8N1 |
| Driver | `cp210x` (built into Linux kernel; native on macOS) |

### Product variants

DLAB ships two pipette families that share the same 6-byte protocol:

| Variant | Channels | Use |
|---|---|---|
| dPette / dPette 7016 | 1 | Single-channel — well-by-well dispensing |
| **dPette+ multi-channel** | 8 or 12 | Parallel dispensing across a row at SBS 9 mm pitch |

The qte77 v0 setup targets the **8-channel dPette+**.

### dPette+ 8-channel specs

| Item | Value | Source |
|---|---|---|
| Volume ranges (programmable) | 0.5–10 µL, 5–50 µL, 15–300 µL, 30–300 µL | [DLAB product page](https://www.dlabsci.com/product/en/dpette-multi-functional-8-channel-electronic-pipette) |
| Channel pitch | 9.0 mm (SBS 96-well) | SBS / ANSI-SLAS 2004-1 |
| Operating modes | aspirate/dispense, continuous mixing, continuous distribution, dilution | DLAB product page |
| Display | LCD with dual rotary knobs | DLAB product page |
| Charging | USB or charging stand | DLAB product page |
| Top-section rotation | 360° (relieves cabling stress when mounted) | DLAB product page |
| Body height (tip → top of ejector) | **~230 mm** | measured on the unit |
| Mass (no tips) | **~250 g** | measured on the unit |
| Body geometry — clamp candidates | upper barrel: Ø ~27 mm round; lower body: 75 × 16 mm rectangular | measured on the unit |
| Tip extension when mounted | ~50 mm (300 µL standard tip) | conventional pipette tip length |
| Total length with tips mounted | **~280 mm** | derived |

The 250 g pipette is the dominant fraction of the carriage payload
budget. Canonical rule (`mount + pipette + tips < 300 g`) and the
mount-design rationale live in [`3d-parts.md`](3d-parts.md).

### Wake the pipette before connecting

The dPette has two states:

1. **Standby** — screen dim or off. Serial connect will time out.
2. **Connectable** — press the operation button. Screen shows volume/mode.

The driver handshake (`A0 HELLO` via `DPetteDriver.connect()`) only
succeeds in state 2. If `preflight.py` reports a handshake timeout,
press the dPette's button and retry.

## Distinguishing the two ports

When both the printer and the pipette are plugged in, your `/dev/tty*`
list has two entries. You disambiguate them by USB VID:PID **when the
bridges differ** (CH340 i3 Mega + CP2102 dPette), or by **probing with
`M115`** when they match (CP2102N i3 Mega + CP2102 dPette — same
VID:PID `10c4:ea60`).

```bash
for d in /dev/ttyUSB*; do
  echo "$d: $(udevadm info "$d" | grep -E 'ID_VENDOR_ID|ID_MODEL_ID|ID_SERIAL_SHORT' | tr '\n' ' ')"
done
```

| Device | VID:PID | Bridge | Baud | Role |
|---|---|---|---|---|
| Anycubic i3 Mega (older) | `1a86:7523` | CH340 | 250000 | gantry (G-code) |
| Anycubic i3 Mega (newer / MARLIN-AI3M) | `10c4:ea60` | CP2102N | 250000 | gantry (G-code) |
| DLAB dPette | `10c4:ea60` | CP2102 | 9600 | pipette (6-byte protocol) |

### Tiebreaker when both ports are CP210x

`tools/preflight.py` already handles this: it probes each candidate
port for Marlin (`M115` @ 250000) first, then dPette (`A0` HELLO @ 9600).
Manually:

```bash
for d in /dev/ttyUSB* /dev/cu.usbserial-* /dev/cu.wchusbserial*; do
  [ -e "$d" ] || continue
  stty -F "$d" 250000 raw 2>/dev/null || continue
  printf 'M115\n' > "$d"
  reply=$(timeout 2 head -c 200 "$d")
  case "$reply" in
    *FIRMWARE_NAME:Marlin*) echo "$d → i3 Mega" ;;
    *) echo "$d → not Marlin (probably dPette)" ;;
  esac
done
```

## Workspace constraints

- The print head, hotend, fan, sensor PCB, and heater wiring have been
  **physically removed** from the carriage. The bare carriage face is
  the mounting surface for the dPette mount (see [`3d-parts.md`](3d-parts.md)).
  The i3 Mega is no longer a 3D printer — it is a 3-axis motion
  platform.
- The dPette mount design is tracked in
  [#40](https://github.com/qte77/i3mega-pipettebot/issues/40)
  (carriage measurement) and
  [#41](https://github.com/qte77/i3mega-pipettebot/issues/41)
  (barrel-bore module).
- Tip racks and well plates live on the moving bed (i3 Mega is a
  bed-slinger: bed = Y axis). Tape them down with removable tape; the
  bed surface is the deck origin.
- Stock Marlin will still try to monitor the absent hotend/bed
  thermistors. Either keep dummy thermistors plugged in **or** send
  `M302 P1` (cold-extrusion override) before motion to suppress
  thermal-runaway aborts. A Stage 1 firmware patch to disable thermal
  monitoring is deferred (see AGENT_REQUESTS.md).
- Soft limits are not enforced in software (deferred). Treat any
  hardcoded coordinate as untrusted.

## Next steps

Once the topology is wired up:

1. Run [`python tools/preflight.py`](../tools/preflight.py) to confirm
   firmware versions and port mapping.
2. Calibrate well-A1 origin: see [`calibration.md`](calibration.md).
3. Run [`python examples/showcase_v0_i3_pipette_sim.py`](../examples/showcase_v0_i3_pipette_sim.py) — the
   end-to-end aspirate/dispense demo.

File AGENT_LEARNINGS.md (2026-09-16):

# Agent Learnings

Gotchas and non-obvious lessons we hit. Keep entries short, dated, and
actionable. Add a new entry every time you'd say "I wish someone had told me
that earlier."

## 2026-09-16 — Two carriage-mount designs coexist on purpose: don't "fix" the duplication

`tools/cad/i3/carriage_dpette_mount.py` (production, M3-bolted upper clamp)
and `tools/cad/i3/carriage_dpette_mount_frictionfit.py` (testing, glue/
friction-fit upper clamp) both build a main+cap+lbracket mount for the same
physical joint. This is deliberate, not accidental duplication — PR #78's
branch had diverged 75 commits from `main` and reached a fundamentally
different design (different bore diameter, axis separation, lower-clamp
geometry with J-hooks, hole placement) through real physical dry-fit
iteration, while `main`'s bolted design shipped independently in the
meantime. The two designs are NOT interchangeable variants of shared
constants — they need different pipette bore/separation measurements, so
the friction-fit module keeps its own local `FRICTIONFIT_*` constants
rather than sharing `measurements.py`'s `UPPER_CLAMP_BORE_D_MM` /
`UPPER_TO_LOWER_SEPARATION_MM` (which the production bolted design is
built and validated against).

Issue #75 (filed from the same branch) explains *why* friction-fit was
abandoned: the bore size never converged after 5 dry-fit rounds, and
glue/friction isn't robust under vibration or serviceable. #75 asks for
M3 bolts back — which matches `carriage_dpette_mount.py`'s production
constants exactly — but its bore re-measurement (Ø27 -> Ø24.5 mm) was
never carried over. **#75 is still open and only half-resolved**: don't
close it without either re-measuring the bolted design's bore on real
hardware or explicitly deciding Ø27 mm is correct after all.

**Rule**: before touching either file, check which one you mean to change.
`parts.json`'s `"status": "testing"` on the frictionfit entries is the only
marker distinguishing "the one being physically validated" from "the
production target" — don't delete the testing variant as "dead code," and
don't silently merge its constants into the shared production ones without
physical dry-fit confirmation on the bolted design.

## 2026-09-09 — `systemd-analyze verify` always fails pre-deploy on a unit whose ExecStart lives in the deploy target

Hit writing `tools/deploy/orchestrator.service` (issue #126). Its
`ExecStart=` points at `/opt/pipettebot/.venv/bin/python`, a path that only
exists after `tools/deploy/deploy.sh` has actually run on the target host.
`systemd-analyze verify` checks that the `ExecStart=` binary exists and is
executable, so it reports `Command ... is not executable: No such file or
directory` in every environment that hasn't deployed yet — CI, a dev
container, a fresh clone before first deploy. This is expected, not a unit
bug.

**Diagnostic**: to confirm the REST of a unit file is valid despite this,
copy it to a scratch path and swap `ExecStart=` for a binary that already
exists (e.g. `/bin/true`), then `systemd-analyze verify` the scratch copy —
a clean run there means only the not-yet-deployed path is at fault.

**Also found in the same pass**: this sandbox's `udevadm` binary is
genuinely absent by default (containers don't run a live udev daemon), not
merely lacking a mock sysfs tree. `apt-get install udev` does provide a
working standalone binary — `udevadm verify <rules-file>` syntax-checks a
rules file with no daemon needed, and `udevadm test <sysfs-devpath>`
parses the full installed ruleset (including a temporarily-copied custom
rules file) against a real `/sys/class/tty/*` path — but neither exercises
an actual VID:PID match without real USB-serial hardware attached.
`Makefile`'s `check_deploy` target treats both `systemd-analyze verify` and
`udevadm` as best-effort/non-fatal for exactly this reason.

## 2026-09-09 — floating `@main` git dependency + no `uv.lock` breaks CI on every upstream bump

`pyproject.toml`'s `orchestrator` extra pinned `so101-biolab-automation` to
`@main` (a floating ref) instead of a commit SHA. `uv.lock` is deliberately
gitignored (library project — see the `.gitignore` comment), so every CI run
re-resolves dependencies from scratch. When so101's `main` bumped its
`fastapi` floor past `[tool.uv] exclude-newer`, then bumped `numpy` too days
later, `uv sync` failed universally on `main` for ~2 months — even the 3.11
job, because uv resolves one universal lockfile across all `requires-python`
markers, so an unsatisfiable split for `python_full_version >= '3.12'` fails
the whole sync regardless of which interpreter actually runs.

**Solution**: pin `so101-biolab-automation` to a commit SHA (mirrors the
`dpette` pin two lines above it in the same file) instead of `@main`, and
bump `[tool.uv] exclude-newer` forward to cover that commit's own floor.
`exclude-newer-package` per-dependency overrides are whack-a-mole here — the
next transitive dep so101 bumps just breaks a different package.

**Still open**: the no-`uv.lock` policy is what let this recur silently;
committing it would freeze CI reproducibility without affecting the
published wheel (uv.lock is never included in sdists/wheels), but that
reverses a deliberate decision — flagged for the repo owner, not changed
here.

## 2026-05-17 — Marlin Y vs CAD top-view Y point opposite directions

Hit in `tools/cad/labware/deck_plate.py::build_deck_plate_assembly`.
Marlin frame is `+Y` FRONT (toward operator), standard CAD top-down is
`+Y` BACK (away from viewer) — an assembly built from raw Marlin coords
looks mirrored front-to-back in FreeCAD / PrusaSlicer / draw.io.

Promoted to `.claude/rules/cad-script-conventions.md` ("Assembly STLs:
mirror Y after Marlin-frame translation"). Rule: any `build_*_assembly()`
applies `mirror(translated, about=Plane.XZ)` after the Marlin-frame
translation. Per-half / printable parts stay in Marlin frame.

## 2026-05-09 — pyserial 3.5 cannot open 250000 baud on Linux Python builds without `termios.B250000`

Symptom: `serial.Serial(port, 250000, timeout=...)` raises
`termios.error: (22, 'Invalid argument')` from `_reconfigure_port`'s
`tcsetattr` call. Hit in `tools/preflight.py` (#30) and
`examples/showcase_v0_i3_pipette_sim.py` (same root cause, separate script;
renamed from `showcase_v0_pipette_sim.py` in PR #157).

Root cause: pyserial 3.5's `BAUDRATE_CONSTANTS` doesn't list 250000, and
the Python `termios` module doesn't expose `B250000` on every build —
it depends on the headers CPython was compiled against, not the distro.
Fedora 43 + Python 3.13 reproduced it; other distros may or may not,
depending on their build config.

**Solution**: open the port at 9600 first, then switch to 250000 via the
Linux-only `TCSETS2 + BOTHER` ioctl. The kernel accepts arbitrary baud
rates this way regardless of which constants Python's `termios` module
exposes. macOS and Windows use the existing pyserial path.

The shared helper lives in `pipettebot.gantry.open_marlin_port()` —
import from there in any new script that opens a Marlin port. Don't
re-implement the ioctl dance per-script.

## 2026-05-08 — Sandbox bind-mounts surface as untracked character-special files

In containerised / sandboxed Claude Code sessions, the user's host shell
and tool dotfiles (`.bashrc`, `.zshrc`, `.gitconfig`, …) and per-session
agent state (`.claude/agents`, `.claude/commands`, `.mcp.json`) get
bind-mounted into the project working tree as **character-special masks**
backed by `/dev/null`. They show as untracked in `git status` even though
they're not real files, and `git stash --include-untracked` errors with
`unsupported file type` because git can't snapshot them.

Pattern (occurrences #19, #24): every fresh sandbox session re-surfaces
the same noise; addressing one set of names doesn't catch the next batch.

**Solution**: gitignore them prophylactically by name. Trailing-slash
patterns (`.idea/`, `.vscode/`) do **not** match the character-special
variant — drop the slash. The full list lives in the `# Per-session
Claude / agent artifacts` and `# Host shell / tool dotfiles` blocks of
`.gitignore`.

**Diagnostic**: `file <path>` reporting `character special (1/3)` →
this is the bind-mount-to-`/dev/null` pattern, not real content.

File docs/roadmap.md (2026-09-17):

# Roadmap

Forward-looking work — not exhaustive. Items here are either tracked
in [open GitHub issues](https://github.com/qte77/i3mega-pipettebot/issues)
(actionable now) or deferred to a future tagged milestone. Per
[CONTRIBUTING.md](../CONTRIBUTING.md) and AGENTS rule #4, anything that
modifies firmware needs an ADR before landing on `main`.

## Near-term (post-v0.1.0)

### Hardware bring-up

- **Geeetech A30 — Smartto motion-profile validation.** Live test
  observed FAST profile feeling slower than SLOW; suspected Smartto
  silently rejects M204/M201 values above some internal limit (research
  log "M400 race" already documents the ack-but-no-effect pattern).
  Need to probe with `tools/gantry_probe.py` at progressively larger
  values to find the ceiling, then either cap the profile range or
  re-anchor MID at a known-good value. May require ADR if MID changes.
- **A30 carriage payload measurement.** Unknown #5 in
  [`docs/research/gantry-firmware-alternatives.md`](research/gantry-firmware-alternatives.md).
  Without a number, the dPette + mount is operator-discretion. Needs a
  spring-scale or similar measurement, then a sibling rule to
  [`.claude/rules/i3-carriage-payload-budget.md`](../.claude/rules/i3-carriage-payload-budget.md)
  and a parallel CAD subtree at `tools/cad/a30/`.
- **A30 dPette mount + cradle CAD.** Once payload budget lands, design
  and print a carriage-mounted dPette holder for the A30. Counterpart
  to the i3 carriage mount under `tools/cad/i3/`.

### Library / tooling

- **Per-leg feedrate env overrides for the A30 showcase.** Currently
  `XY_FEED` / `Z_FAST_FEED` / `LIQUID_DIVE_FEED` / `TOUCHDOWN_APPROACH_MM`
  are Python constants. Adding env-var resolution with sane defaults
  (~6 lines) lets operators dial per-run without editing code, the
  same way `MOTION_PROFILE` works today.
- **M114-based motion-completion polling.** Current Smartto workaround
  is a 30 s host-side sleep before the post-cycle re-home. Polling
  `M114` until reported position stops changing would be more precise
  and could shorten the wait when the queue is shallow.
- **Branch-protection "Require signed commits".** CONTRIBUTING already
  documents the requirement; enabling the GitHub setting enforces it
  mechanically (currently honor-system at review time).

## Deferred to Stage 1+ (firmware track — ADR now exists, trigger not yet met)

[ADR 0005](adr/0005-pc-as-host.md) now documents this decision and the
Stage 0-2c escalation path in full (superseding the summary that used
to live only in README). Per AGENTS rule #4, any Stage 1+ work still
needs its own follow-up ADR before merging — 0005 sets the bar, it
doesn't pre-approve a specific patch.

- **Stage 1 — Marlin config patch** for the i3 Mega. Closed as issues
  #7/#9: ADR 0005 found every currently-needed parameter is already
  runtime-settable over G-code, so there's no live trigger. Reopen if
  a genuinely G-code-unreachable need appears (see ADR 0005's trigger
  conditions table).
- **Stage 2 — UART tap to dPette.** Direct firmware-side pipette
  command stream, eliminating the host-as-relay round-trip. Same
  no-current-trigger status as Stage 1; see ADR 0005.
- **Smartto firmware patches** (A30 family). `G28 Z` is broken on
  stock; a follow-up ADR would need to cover the patched version +
  downstream delivery path before any merge.

## Deferred to a future API tier

From [docs/UserStory.md](UserStory.md) "Out of scope (v0)":

- **Deck calibration library** — typed deck-frame, slot-by-name
  addressing, calibration storage. Caller currently passes raw
  `(x, y, z)`.
- **Software soft-limit enforcement** — host-side coordinate
  validation before motion commands.
- **Multi-deck / multi-plate workflows** — currently single deck per
  session.
- **GUI** — Python API only for v0.
- **Aspirate verification (pressure monitoring).** Hamilton's TADM
  uses a per-channel air-column pressure transducer for clog /
  dry-well detection. The dPette+ has no exposed sensor port; v0 is
  fully open-loop with no aspirate verification. A bolt-on inline
  sensor is conceivable but requires characterization of the
  dPette+ internal pressure signature first. See
  [`docs/research/aspirate-monitoring.md`](research/aspirate-monitoring.md).
- **Active tip-disposal conveyance.** v0 relies on the passive
  `dpette_tip_release` waste slot. A standalone belt module from
  commodity parts (~$37–72 BOM) is feasible for high-cycle workflows
  but requires either a Stage 1+ firmware track or a parallel-MCU
  side path. See
  [`docs/research/tip-disposal-belt-module.md`](research/tip-disposal-belt-module.md).

## Doc improvements

- **ADRs for the safe_home design** (0004) and **motion-profile 3x
  ratio retune** are in place; further design decisions get their own
  numbered ADR under `docs/adr/`.
- **Per-firmware operator guides** — Smartto/A30 has the research log
  plus ADR 0004; an i3-Mega counterpart guide would be symmetric.

## Anti-roadmap (won't do, even if asked)

- **Maintenance of a fork of Marlin** — stays upstream; patches go via
  ADRs and flashable artifacts, never as vendored submodules (license
  and maintenance overhead).
- **Re-encoding the dPette serial protocol in this repo** — see
  [`.claude/rules/pipette-delegation.md`](../.claude/rules/pipette-delegation.md).
  Always import `dpette.DPetteDriver`; never construct raw 6-byte packets.

## How items move on/off this list

- New work: open a GitHub issue first; the issue is the canonical
  tracker. Roadmap mentions the issue as a forward-look summary.
- Completed work: lands in CHANGELOG's Unreleased section, then in a
  tagged release entry. Removed from this roadmap when shipped.
- Withdrawn work: documented in the relevant research log or ADR with
  the rationale, then removed here.

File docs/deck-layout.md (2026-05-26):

---
title: "Deck layout"
status: "STALE"
updated: "2026-05-17"
owner: "lambda biolab"
---

> **STALE.** The full-plate tour has since gained tip pickup, liquid
> aspiration, B3 blow-out at each well, and tip release — this document
> still describes the simpler aspirate/dispense-only layout. Refresh
> before relying on it.

Physical arrangement of labware on the 220 × 220 mm deck plate that sits
on the i3 Mega bed. The full-plate tour
([`examples/showcase_v0_i3_full_plate.py`](../examples/showcase_v0_i3_full_plate.py))
addresses this deck directly; the per-axis well-A1 origin and dispense Z
are still measured per-build in [`calibration.md`](calibration.md). The
older two-well demo
([`examples/showcase_v0_i3_pipette_sim.py`](../examples/showcase_v0_i3_pipette_sim.py))
predates this layout and uses its own hardcoded coordinates.

Coordinate convention: `X = 0` at the left edge, `Z = 0` at the
deck-plate top surface. Y axis is **positive 0–250 mm** (per this
printer's configuration): **Y=0 is the BACK** of the bed and **Y=250
is the FRONT**. Higher Y values move the bed toward the operator.
All Marlin-Y values in this doc and the scripts are positive.

## Top view

Anchor points only (Marlin frame, Y=0 back / Y=250 front). Slot
extents are no longer tracked in the deck-frame abstraction — the
tour uses absolute Marlin Y/X targets per the user-calibrated anchors.

```text
                       FRONT (operator, Y=250)
       +---------------------------------------------------------+
Y=250  |                                                         |
Y=220  |                                  ● TIP PICKUP           |  (X=155, Y=217.5)
       |                                                         |
Y=200  |                                                         |
Y=190  | ● SBS col 1  (X=50, Y=190)  ← cycle 1                   |
       | ●  col 2..4 (Y=181, 172, 163)                           |
Y=154  | ● col 5 (Y=154)                                         |
       | ●  col 6..7 (Y=145, 136)                                |
Y=115  | ●  col 8 (Y=127)             ● RESERVOIR (X=155, Y=115) |
       | ●  col 9..10 (Y=118, 109)                               |
       |                                                         |
  Y=100| ● col 11 (Y=100)            ← cycle 11 (last dispense)  |
       |                                                         |
    50 |                                                         |
       |                                                         |
       |                                                         |
Y=0    +---------------------------------------------------------+
                         BACK (Y=0)   ← G28 home corner
       X=0         X=50                        X=155          X=220
```

## Anchor points

The tour visits four named XY positions plus a home corner. Each is
specified in the Marlin frame (positive 0–250 Y convention). The
deck-frame slot extents that earlier iterations tried to track are
no longer authoritative — the user gave direct Marlin-Y anchors to
override them.

| Anchor | Marlin X | Marlin Y | Transit Z | Dive Z |
|---|---|---|---|---|
| Home / park | 0 | 0 | 95 | 74.25 (PARK_Z) |
| Reservoir aspirate | **155** | **115** | 95 (TRAVEL_Z) | **70** |
| SBS col 1 (first dispense) | **50** | **190** | 95 (TRAVEL_Z) | **70** |
| SBS col 11 (last dispense) | 50 | **100** | 95 (TRAVEL_Z) | 70 |
| Tip pickup TO leg (no tips) | **155** | **217.5** | 90 (TIP_PICKUP_PRE_Z) | **70** (engagement) |
| Tip pickup FROM leg (tips loaded) | **155** | **217.5** | 130 (TIP_PICKUP_LIFT_Z) | — (lifts away) |

SBS pitch is **−9 mm/cycle** (standard SBS column pitch; Y decreases each
visit). **11-cycle** ladder: **190, 181, 172, 163, 154, 145, 136, 127,
118, 109, 100**.

Tip-box loaded-tips height: **≥ 65 mm** (minimum — `TIP_PICKUP_PRE_Z`
and `TIP_PICKUP_LIFT_Z` are derived from this; if a taller tip box is
introduced, raise both first).

### dPette geometry

For fixture-clearance reasoning: the loaded dPette+ 8-channel head extends
**54 mm below the carriage reference** (tip end to the bottom of the dPette
body where it meets the mount). Per [`calibration.md`](calibration.md),
`Z = 0` in Marlin is calibrated to **tip-on-deck**, so the `Z` values in
this doc are tip-end altitudes and do *not* need a 54 mm offset added.
The 54 mm matters when designing CAD parts that might foul the dPette
body during XY travel.

## Motion constants

Constants encoded in [`examples/showcase_v0_i3_full_plate.py`](../examples/showcase_v0_i3_full_plate.py):

| Constant | Value (mm) | Why |
|---|---|---|
| `DECK_OFFSET_X` | **+25** | Marlin commanded X = deck X + 25 (bed sits 2.5 cm right of nominal deck-frame plan) |
| `DECK_OFFSET_Y` | **0** | Y convention is positive 0–250 (Y=0 back, Y=250 front); no offset needed |
| `TRAVEL_Z` | **95** | Transit altitude — all inter-slot XY motion happens here. Clears SBS plate (top Z=13) by 82 mm, reservoir rim (Z=24) by 71 mm. The column tour never crosses the tip box (tip box Y=217.5 vs SBS Y_max=190), so the 30 mm clearance over the 65 mm loaded-tip-box minimum is informational only — phase 2 handles tip-box transit at `TIP_PICKUP_PRE_Z`/`LIFT_Z` |
| `WELL_Z` | **70** | Dive Z into SBS well; **invariant `WELL_Z ≥ RESERVOIR_Z`** (equality here) |
| `RESERVOIR_Z` | **70** | Dive Z into reservoir |
| `TIP_PICKUP_PRE_Z` | **90** | TO-leg approach Z (no tips on yet): body bottom is the lowest physical point, so 25 mm body clearance over the 65 mm tip box is enough |
| `TIP_PICKUP_Z` | **70** | Engagement Z; body bottom on tip tops |
| `TIP_PICKUP_LIFT_Z` | **130** | FROM-leg post-engagement lift (tips loaded): tip ends extend 49.5 mm below the body, so this sits 40 mm higher than PRE_Z to keep tip ends clear of the tip box (65 mm tip-end clearance) |
| `TIP_PICKUP_X` | 130 (slot pre-offset) → **155 (Marlin)** | Per user spec (shared with reservoir X) |
| `TIP_PICKUP_Y` | 217.5 (slot pre-offset) → **217.5 (Marlin)** | Per user spec |
| `RESERVOIR_REF_X` | 130 (slot pre-offset) → **155 (Marlin)** | Per user spec (shared with tip pickup X) |
| `RESERVOIR_REF_Y` | 115 (slot pre-offset) → **115 (Marlin)** | Per user spec |
| `SBS_REF_X` | 25 (slot pre-offset) → **50 (Marlin)** | Per user spec |
| `SBS_COL1_Y` | 190 (slot pre-offset) → **190 (Marlin)** | Cycle 1 dispense Y per user spec. Step −9 mm per cycle; 11-cycle ladder 190, 181, …, 100 |
| `SBS_COL_PITCH` | **−9 mm** | Standard SBS column pitch. Step between consecutive cycle Y positions (Y decreases each visit) |
| `M211 S0` (sent at bootstrap) | — | Disables Marlin software endstops defensively in case any commanded Y falls outside the firmware-configured Y_MIN/Y_MAX. Lasts until power-cycle |
| `PARK_Z` | **74.25** | End-of-tour park altitude. `1.5 × 49.5 mm` (disposable tip length) — clears any forgotten tip with half its length to spare |

> ℹ **Z-first transit pattern** (collision-safe): every slot visit
> follows `G1 Z=TRAVEL_Z` → `G1 X Y` → `G1 Z=dive` → `G1 Z=TRAVEL_Z`.
> XY motion ALWAYS happens at `TRAVEL_Z=95`, which is above every
> slot the column tour visits (SBS plate Z=13, reservoir Z=24). The
> tip box (Z=65 loaded) is not crossed by the column tour. The
> combined `G1 X Y Z` form is avoided. `visit_reservoir` and
> `visit_column` both delegate to a single `_visit_xy_dive(x, y, dive_z)`
> helper differing only in target XY and dive Z.

Aspirate and dispense are each a **single descent** to the respective Z
(no up-and-back plunger stroke). The `WELL_Z ≥ RESERVOIR_Z` invariant
guarantees the tip is never deeper at dispense than at aspirate, which
also satisfies the motion-safety "tip above liquid before dispense" rule
([`../.claude/rules/motion-safety.md`](../.claude/rules/motion-safety.md)).

### Frame conventions

Motion targets are spec'd in the **Marlin frame**: `X = 0` at the left
edge, `Y = 0` at the bed BACK, `Y = 250` at the bed FRONT (positive-Y
convention per this printer's calibration), `Z = 0` at the calibrated
tip-on-deck zero. The X axis still carries a `DECK_OFFSET_X = +25`
correction (legacy from when the deck-frame abstraction was active);
the Y axis has no offset (`DECK_OFFSET_Y = 0`).

If the bed-vs-deck alignment changes (deck plate moved, bed
re-calibrated), update the per-anchor Y values rather than introducing
a new global offset.

## Tour sequence

The full-plate tour ([`examples/showcase_v0_i3_full_plate.py`](../examples/showcase_v0_i3_full_plate.py))
runs in four phases (each phase is delimited by a `; ===== phase N =====`
comment in the tee'd G-code):

1. **Bootstrap** — install the liquid-handling motion profile via
   `pipettebot.motion_profile.select_profile(MOTION_PROFILE)` (the four
   M203/M201/M204/M205 lines below; default `mid`), then `M211 S0`
   (disable software endstops so negative-Y reservoir/SBS targets aren't clamped),
   `G28 X Y Z` (explicit axes — plain `G28` skips Z on this firmware).
   **No separate `G1 Z=TRAVEL_Z` lift** — phase 2's step 1 handles
   the post-G28 Z ascent directly. **Precondition: tips MUST be removed
   from the dPette before this phase**, because `Z=0` is calibrated to
   tip-end-on-deck (per [`calibration.md`](calibration.md)) — `G28 Z`
   would drive any mounted tip into the deck.
2. **Tip pickup** (once) — six-step Z-first sequence per user spec.
   Asymmetric pre/post: the TO leg (approach, no tips) ascends only
   to `TIP_PICKUP_PRE_Z=90` (body needs to clear the box), while the
   FROM leg (lift + reservoir transit, tips loaded) uses
   `TIP_PICKUP_LIFT_Z=130` (tip ends 49.5 mm below body need to
   clear the box).
   1. `G1 Z90` (ascend to TO-leg clearance — 25 mm body-bottom margin
      over the 65 mm loaded tip box).
   2. `G1 X155 Y217.5` at Z=90 (XY to tip box at TO-leg altitude).
   3. `G1 Z70` (engage tips — friction-fit, no plunger stroke).
   4. `G1 Z130` (lift with tips loaded — 65 mm tip-end margin over
      the tip box).
   5. `G1 X155 Y115` at Z=130 (travel to reservoir; X stays at 155,
      only Y moves — tip box and reservoir share X).
   6. `G1 Z95` (descend to `TRAVEL_Z`, hand off to cycle 1's Z-first
      transit pattern).
3. **Column tour** (11×) — for each SBS column N, in order 1..11, the
   `_visit_xy_dive` helper runs twice per cycle (once for reservoir,
   once for SBS column). Each call is the same 4-step Z-first sequence:
   1. `G1 Z=TRAVEL_Z` (lift to transit altitude).
   2. `G1 X Y` only, at TRAVEL_Z (no Z motion during XY).
   3. `G1 Z=dive_z` (descend — RESERVOIR_Z=70 for reservoir, WELL_Z=70
      for SBS column).
   4. `G1 Z=TRAVEL_Z` (lift back to transit altitude, ready for next).

   Cycle layout: reservoir at (155, 115); SBS columns at X=50,
   Y=190,181,…,100 (col 1 → col 11, −9 mm SBS pitch).
4. **Park at home corner** — Z-first sequence: `G1 Z=TRAVEL_Z` (no-op,
   already there) → `G1 X0 Y0` (XY at TRAVEL_Z) → `G1 Z=PARK_Z` where
   `PARK_Z = 1.5 × tip length = 74.25 mm`. Plain G1, not `G28` — trusts
   the tour's tracked position to save ~20 s of Z homing, and parks Z
   high enough to clear any tip still loaded on the dPette (forgotten-tip
   safety margin). Manually run `G28` afterwards if endstop re-reference
   is needed.

Column iteration steps `-9 mm` per cycle (standard SBS pitch; Y decreases each visit).
Cycle 1 lands at `Marlin Y = 190`, cycle 11 at `Y = 90`.

### Y motion timeline

Bed Y positions through the tour (back ↑ , front ↓), in Marlin frame:

```text
              Marlin Y (mm)   (Y=0 back, Y=250 front)
                 ↑ FRONT (operator)
   +250 ─────────│
   +220 ─────────●  tip pickup (Y=217.5, phase 2, once)
                 │
   +200 ─────────│
   +190 ─────────●  SBS col 1   ← phase 3 first dispense
                 │  SBS col 2..4 (181, 172, 163)
   +154 ─────────●  SBS col 5 (154)
                 │  SBS col 6..7 (145, 136)
   +127 ─────────●  SBS col 8 (Y=127)
   +118 ─────────●  SBS col 9 (closest to reservoir Y; 3 mm delta)
   +115 ─────────●  reservoir aspirate (every cycle)
   +109 ─────────●  SBS col 10 (closest to reservoir Y; -6 mm delta)
                 │
   +100 ─────────●  SBS col 11  ← phase 3 last dispense
                 │
    +50 ─────────│
                 │
                 │
      0 ─────────●  G28 home / phase 4 park / BACK of bed
                 ↓ BACK
```

Per-tour-cycle sequence:

```text
home(Y=0) → tip pickup(Y=217.5) →
  cycle 1:  reservoir(Y=115) → SBS col 1  (Y=190)
  cycle 2:  reservoir(Y=115) → SBS col 2  (Y=181)
  cycle 3:  reservoir(Y=115) → SBS col 3  (Y=172)
  cycle 4:  reservoir(Y=115) → SBS col 4  (Y=163)
  cycle 5:  reservoir(Y=115) → SBS col 5  (Y=154)
  cycle 6:  reservoir(Y=115) → SBS col 6  (Y=145)
  cycle 7:  reservoir(Y=115) → SBS col 7  (Y=136)
  cycle 8:  reservoir(Y=115) → SBS col 8  (Y=127)
  cycle 9:  reservoir(Y=115) → SBS col 9  (Y=118)
  cycle 10: reservoir(Y=115) → SBS col 10 (Y=109)
  cycle 11: reservoir(Y=115) → SBS col 11 (Y=100)
park(Y=0)
```

Bootstrap snippet (what every `examples/*.py` gantry script emits with
the default `MOTION_PROFILE=mid`):

```text
M203 X500 Y500 Z20           ; peak feedrate caps (Z at leadscrew limit, shared across profiles)
M201 X600 Y800 Z200           ; MID per-axis accel — Z at leadscrew floor, X/Y careful for plate slosh + tip pendulum
M204 P600 R600 T600           ; MID default print/retract/travel accel
M205 X3 Y5 Z0.2 E0           ; MID classic jerk — tight X (tip pendulum + droplet), tight Z (meniscus)
M211 S0                      ; disable soft endstops (defensive)
G28 X Y Z                    ; home all axes — TIPS MUST BE REMOVED
M400
G1 Z95 F1200                 ; raise to TRAVEL_Z before any XY motion
M400
```

The four M-codes (M203/M201/M204/M205) are emitted via
`pipettebot.motion_profile.select_profile(MOTION_PROFILE)`:

- `MOTION_PROFILE=slow` / `mid` / `fast` — bundled named profile
- unset → MID (default; what's shown above)
- `MOTION_PROFILE=off` or empty — skip the install entirely (Marlin
  keeps RAM/EEPROM motion settings)

See `src/pipettebot/motion_profile.py` for the full SLOW/MID/FAST
values + semantics, and [ADR 0003](adr/0003-motion-profile-bundled-constants.md)
for the design decision.

`G28 X Y Z` (explicit axes — plain `G28` skips Z on the AI3M Marlin
variant) leaves the nozzle at the calibrated Z=0; the immediate Z
raise is mandatory before any XY motion, since the first motion
would otherwise drag any tip extension through near-home obstacles.

## Rationale

1. **Home corner is bed back** (Y=0). In the positive-Y convention,
   `G28` brings the bed all the way back; the dPette is over the rear
   of the deck at homed state.
2. **Reservoir at Y=115, SBS col 1 at Y=190** — both well within the
   0–250 Y range. Reservoir sits 75 mm back of SBS col 1, so the
   reservoir→col-1 transition is a single forward Y move.
3. **`TRAVEL_Z = 95`** = `WELL_Z + 25 mm` (25 mm transit margin above
   the reservoir/well dive Z). Reservoir↔SBS transit doesn't cross the
   tip box (tip box Y=217.5 vs SBS Y_max=190), so the 30 mm column-tour
   clearance over the 65 mm tip-box minimum is informational; phase 2
   handles tip-box transit at PRE_Z=90 / LIFT_Z=130. The previous
   125 mm transit altitude paid an extra 30 mm of Z stroke per dive (4
   per cycle × 30 mm = 120 mm/cycle), saving ~6 s per cycle at the
   Z_FEED=20 mm/s leadscrew cap.
4. **End with `G1` to home corner**, not `G28`. The tour does pure G1
   moves with no expected step loss, so a closing `G1 X0 Y0 Z PARK_Z`
   lands the carriage at the home corner ~20 s faster than re-homing
   every axis. Run `G28` manually if endstop re-reference is ever
   needed.
5. **`M211 S0` in the bootstrap** disables Marlin software endstops so
   commanded Y values aren't silently clamped to the firmware
   `Y_MIN`/`Y_MAX` range. With all current anchors in 0–220, this
   is precautionary; earlier iterations needed it because of negative
   Y commands.

## Pipette orientation

The 8-channel dPette is mounted with its **8 channels aligned along X**.
The mount/carriage CAD under `tools/cad/i3/` is designed for this
orientation. Stepping A1 → A2 → … → A12 across a plate row is therefore
a Y-axis move (9 mm per column on the SBS pitch).

If the mount orientation is ever rotated 90° (8 channels along Y), the
SBS plate must rotate with it — the row axis must match the channel
axis.

## Open offsets

1. **Bed origin alignment** — Y axis settled at no offset
   (`DECK_OFFSET_Y = 0`) once the positive-Y convention took over.
   X retains a `+25 mm` correction. Re-derive if the deck plate is
   repositioned or the printer's Y axis is reconfigured.
2. **Deck-plate thickness.** All `Z` values above are measured from
   the calibrated tip-on-deck zero. If the deck plate is repositioned
   in Z (e.g. mounted on a riser), every `Z` constant needs an offset
   added.
3. **Tip-pickup Y placement** — anchored at Marlin Y=217.5 (front-right,
   shared X=155 with the reservoir). Confirmed against the physical
   tip-box position. Update `TIP_PICKUP_Y` if the deck rotates or the
   tip box moves.

These items belong in [`calibration.md`](calibration.md) step 5 once
the physical anchors are confirmed.

## Related docs

- [`hardware.md`](hardware.md) — printer + pipette wiring, port
  disambiguation
- [`calibration.md`](calibration.md) — per-build well-A1 origin and
  dispense Z measurement
- [`3d-parts.md`](3d-parts.md) — carriage mount and Z-envelope math
- [`../.claude/rules/motion-safety.md`](../.claude/rules/motion-safety.md) —
  M400 sequencing, tip-above-liquid rule, soft-limit absence

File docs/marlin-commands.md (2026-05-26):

---
title: "Marlin command reference"
status: "DRAFT"
updated: "2026-05-09"
owner: "lambda biolab"
---

Quick reference for the G/M-codes you actually reach for when bringing up
or debugging an i3 Mega running MARLIN-AI3M v1.4.6 (Marlin 1.1.9 base).
Not exhaustive — see the [Marlin G-code index](https://marlinfw.org/meta/gcode/)
for the full set. The same table is built into
[`tools/gantry_repl.py`](../tools/gantry_repl.py) under the `?` /
`help` command.

For project provenance, fork lineage, license posture, and credible OSS
alternatives to Marlin, see [`research-oss-toolchain.md`](research-oss-toolchain.md).

## Coordinate orientation (i3 Mega, front view)

| Axis  | Min direction | Max direction |
|---|---|---|
| X | LEFT frame | RIGHT frame |
| Y | FRONT (bed toward operator)| BACK |
| Z | BED | TOP |

So `G0 X-1` moves the head **left**; `G0 Y-1` moves the bed **toward you**;
`G0 Z-1` moves the head **down toward the bed**. `G28 X` drives left until
`x_min` triggers — which is exactly the path that hammered when the
carriage tab couldn't reach the switch.

## How to send these

Any of:

- Interactive REPL: `I3MEGA_PORT=/dev/ttyUSB0 uv run python tools/gantry_repl.py`
- Stepped axis motion: `AXIS=X I3MEGA_PORT=/dev/ttyUSB0 uv run python tools/diagnose_axis.py`
- Port discovery + chaining: `eval "$(uv run python tools/preflight.py --export)" && ...`
- A serial terminal that handles 250000 baud (e.g. `tio -b 250000 /dev/ttyUSB0`).

`pyserial` direct opens at 250000 fail on Linux Python builds without
`termios.B250000` — the `pipettebot.gantry.open_marlin_port` helper used by
the tools/ scripts works around that. See [AGENT_LEARNINGS.md](../AGENT_LEARNINGS.md).

## Identification and state

| Command  | Effect |
|---|---|
| `M115` | Firmware name + capabilities. Returns `MACHINE_TYPE`, `FIRMWARE_NAME`, `UUID`. Also serves as the preflight tiebreaker. |
| `M114` | Current XYZE position as Marlin sees it. Useful mid-debug; differs from physical position when steppers slipped or homing failed. |
| `M119` | Endstop status: `x_min`, `y_min`, `z_min`, `z2_min`. Each reports `open` or `TRIGGERED`. Press a switch by hand and re-send to confirm wiring. |
| `M503` | Dump EEPROM-backed settings (steps/mm, feedrates, accel, Z offset, …). Grep its output for `M412` to confirm whether the runtime runout-toggle is wired in your build. |

## Halt and recovery

| Command  | Effect |
|---|---|
| `M999` | Clear `Error:Printer halted` flag after a `kill()` (e.g. T0 abnormal). The underlying cause re-fires next sample tick — fix the cause first. |
| `M112` | Emergency stop. Marlin halts and refuses commands until power-cycle. Avoid unless you mean it. |

## Motion

| Command | Effect |
|---|---|
| `G90` | Absolute positioning (default). Coordinates are room-fixed.  |
| `G91` | Relative positioning. Coordinates are deltas from current. |
| `G0 X10 F600` | Move to/by X=10 at 600 mm/min. `G90` vs `G91` decides the meaning. |
| `G1 ... F...` | Same motion as `G0`. `G1` is for "extruding" moves but moves identically. |
| `M400` | Block until all queued moves finish. Required between `G0/G1` and any pipette aspirate/dispense. |
| `G92 X0 Y0 Z0` | Set the current position as origin. No physical motion. |

## Homing

| Command | Effect |
|---|---|
| `G28` | Home all axes (X → Y → Z). On stock AI3M, Z homing uses the head-mounted inductive probe. |
| `G28 X` | Home X only. Drives toward the X-min frame microswitch. |
| `G28 Y` | Home Y only. Drives toward the Y-min frame microswitch. |
| `G28 Z` | Home Z only. **Do not run on a headless gantry** — without the inductive probe, `z_min` never triggers and the gantry drives into the bed. |

## Steppers and power

| Command | Effect |
|---|---|
| `M17` | Energize all steppers. Holds position electrically. |
| `M18` / `M84` | De-energize all steppers. Frees the gantry for hand-movement. |
| `M84 S30` | Auto-disable steppers after 30 s idle. |

## Sensor and safety overrides

| Command | Effect |
|---|---|
| `M302 P1` | Allow cold extrusion. Bypasses the "below MIN_TEMP" extruder lockout. Irrelevant for headless-gantry use. |
| `M211 S0` | Disable software endstops. The gantry can move past `*_MAX_POS` / `*_MIN_POS`. Use only for explicit out-of-range tests. |
| `M412 S0` | Disable filament runout sensor at runtime. **Marlin 2.0+ only — your AI3M v1.4.6 (1.1.9) returns `Unknown command`.** Use the LCD `Configuration → Filament Sensor → Off` toggle instead, or jumper the sensor's signal-to-GND. |

## EEPROM

| Command  | Effect |
|---|---|
| `M500` | Save current RAM settings to EEPROM (persists across power-cycle).  |
| `M501` | Reload EEPROM settings into RAM (undoes unsaved RAM edits). |
| `M502` | Reset RAM settings to firmware defaults. Does **not** touch EEPROM until you also send `M500`. |

## Project-specific gotchas

- **`z2_min`** appears in `M119` output even on stock AI3M (single Z motor). It's a Marlin compile-time artifact and reads the same as `z_min` on this hardware — ignore unless you've added a second Z probe.
- **`G28` after head removal** will succeed for X and Y but hang or crash on Z, since the probe is gone with the head. Use `G28 X Y` until you've decided on a Z-endstop strategy (file an [AGENT_REQUESTS.md](../AGENT_REQUESTS.md) item for the firmware track).
- **T0 abnormal at boot** is independent of any of these commands — it triggers in Marlin's safety loop before the USB queue is drained. Hardware fix (100 kΩ across the T0 connector) or firmware patch (`TEMP_SENSOR_0 0`) is the only path.
- **Custom baud (250000)** is the AI3M default. macOS and most Windows Python builds open it directly via `pyserial`; some Linux builds need the `TCSETS2 + BOTHER` ioctl fallback handled by `pipettebot.gantry.open_marlin_port`.

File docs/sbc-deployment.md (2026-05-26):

---
title: "Single-Board Computer (SBC) on-printer deployment (Path 2)"
status: "DRAFT"
updated: "2026-05-17"
owner: "lambda biolab"
---

Replace the laptop tether with a **Single-Board Computer** (SBC) —
a small Linux board (e.g., Raspberry Pi) zip-tied to the printer
chassis. The board acts as USB **host** for both the i3 Mega
and the dPette, runs `pipettebot` directly, and turns the
printer + pipette + board into a single self-contained appliance. No
firmware patch, no soldering, no warranty voided — the dPette and
printer keep their stock cables. You give up host-less SD-card
autonomy (that is **Path 3** — `M820` UART tap, tracked under the
`firmware` label and ADR [#6](https://github.com/qte77/i3mega-pipettebot/issues/6)).

> **Status: Draft.** No physical Pi has been bolted to the reference
> i3 Mega yet. BOM, wiring, and mount design are to be confirmed when
> the first unit is built.

## Why this exists

Path 1 (laptop-as-host) is fine for development but ties a $1k+
machine to a benchtop while a $300 robot runs. The dPette and the
i3 Mega are both USB **devices** — they cannot be wired directly to
each other (see [`hardware.md`](hardware.md) and
[issue #18](https://github.com/qte77/i3mega-pipettebot/issues/18)).
The cheapest USB host that runs `pipettebot` is a Raspberry Pi 1
Model B+ (2014, often free if on hand — see "Pi 1 B+ specifics" below)
or a Pi Zero 2 W (~$15 new). Mounting one to the printer removes the
laptop without changing any cabling on either device.

## Architecture

```text
                                  ┌─ USB-A ──cable──► i3 Mega USB-B (Marlin/Trigorilla)
   Pi Zero 2 W       (host)───────┤
   (zip-tied to                   │
    printer chassis,              └─ USB-A ──cable──► dPette microUSB
    powered by                       (existing dPette cable, unchanged)
    printer 5 V rail
    or own 5 V brick)

   Pi runs pipettebot      ──┐
                             ├──► same `examples/showcase_v0_i3_pipette_sim.py` workflow
                             │    as today, just on the Pi
   SSH from laptop / VS      │
   Code Remote-SSH for       │
   editing & control         │
                             ┘
```

`pipettebot` doesn't change. The Pi sees two `/dev/ttyUSB*` (or
`/dev/serial/by-id/*`) devices — one for the printer, one for the
pipette — exactly like the laptop sees `/dev/cu.*` today.

## BOM

| Item | Approx. cost | Notes |
|---|---|---|
| Raspberry Pi (Pi 1 B+ 2014, Pi Zero 2 W, or Pi 4/5) | $15-45 | Pi 1 B+ already on hand is the cheapest option — see "Pi 1 B+ specifics" below for caveats. |
| microSD card, 16-32 GB, A1 class | $6 | Boot drive. SanDisk / Samsung; avoid no-brand. |
| USB-A OTG adapter, micro-USB → USB-A female | $3 | Pi Zero only — Pi 1 B+ and Pi 4/5 have native USB-A. |
| Powered USB hub (2-port minimum) | $8 | See "Pi 1 B+ specifics" below. Optional on Pi 4/5. |
| Pi 5 V power supply, 2.5 A | $7 | Or piggyback off the printer's PSU 5 V rail through a buck regulator (riskier; document if you go that route). |
| 3D-printed mount | free (PETG/PLA) | Bolts to a frame extrusion or zip-ties to the chassis. STL placeholder, see backlog. |
| Zip ties / Velcro | $1 | v0 mount. |

Total: **~$25-40** depending on Pi model and whether you reuse cables/PSU you already have.

## Pi 1 B+ specifics (2014 hardware)

The Pi 1 Model B+ is the cheapest viable host (often free if you already
have one). Works for v0 because pipetting is slow (seconds per move),
so the Pi's modest CPU and high-ish USB-serial latency don't bottleneck.

Hardware essentials: 4× USB 2.0 native (no OTG adapter needed), no
built-in Wi-Fi (add a USB Wi-Fi dongle).

| Behaviour | Typical | Source |
|---|---|---|
| Round-trip latency for a short G-code command | 15–17 ms | [Pi-to-Arduino latency measurement thread](https://forums.raspberrypi.com/viewtopic.php?t=276481) |
| Required wait after opening a serial port before first send | ~2.7 s | [Serial port-open latency observations](https://forums.raspberrypi.com/viewtopic.php?t=161922) |

The 2.7 s post-open wait matches the existing `time.sleep(3)` in
[`examples/showcase_v0_i3_pipette_sim.py`](../examples/showcase_v0_i3_pipette_sim.py)
right after `open_marlin_port` — the showcase already accommodates this.

**Mandatory: powered USB hub.** The Pi 1 B+ supplies limited 5 V on its
USB ports. Plugging both the i3 Mega (CH340/CP2102N) and the dPette
(CP2102) directly into the Pi causes intermittent brownouts and
enumeration drops. Use a powered hub for both peripherals.

## Pi software setup (headless, no monitor)

One-time bring-up. After this the Pi runs unattended.

1. **Flash Raspberry Pi OS Lite** with `rpi-imager`. Match the Pi
   architecture: **armhf 32-bit for Pi 1 B+ / Zero** (ARMv6), arm64 for
   Pi Zero 2 W / 4 / 5. In the imager's "advanced settings":
    - hostname (e.g. `pipettebot-01`)
    - SSH with public-key auth (paste `~/.ssh/id_ed25519.pub`)
    - Wi-Fi credentials, **or** skip Wi-Fi and use Ethernet (Pi 1 B+
      has built-in RJ45; mDNS works over Ethernet)
    - locale / keyboard

2. Boot the Pi; wait ~60 s for first-boot expansion. SSH in:

    ```bash
    ssh pipettebot-01.local      # or use the IP from your router
    ```

3. **Run the provisioning helper** — installs system deps, clones the
   repo, syncs Python deps, runs the mocked test suite, and writes
   `config.local/pipettebot.env` with stable `/dev/serial/by-id/...` port
   paths discovered via `tools/preflight.py`:

    ```bash
    curl -fsSL https://raw.githubusercontent.com/qte77/i3mega-pipettebot/main/tools/setup_pi.sh | bash
    ```

    The script is idempotent — safe to re-run. On a Pi 1 B+ (700 MHz
    single-core) the dep sync takes 5–15 min. On ARMv6 the script falls
    back to system Python + pip if uv has no `armv6l` build.

4. **Run** the v0 showcase:

    ```bash
    cd ~/i3mega-pipettebot
    source config.local/pipettebot.env
    uv run tools/preflight.py                       # sanity check
    uv run examples/showcase_v0_i3_pipette_sim.py
    ```

    The env file is host-specific and ignored by git (top-level
    `.gitignore` covers `config.local/`). Format:

    ```bash
    export I3MEGA_PORT=/dev/serial/by-id/usb-1a86_USB2.0-Serial-...
    export PIPETTE_PORT=/dev/serial/by-id/usb-Silicon_Labs_CP2102_USB_to_UART_Bridge_Controller_<serial>-if00-port0
    ```

## Wiring

1. Mount the Pi to the printer chassis with zip-ties or a 3D-printed
   bracket. Avoid moving parts (X-carriage, bed, leadscrew). Keep it
   away from the heatbed cabling.
2. Plug the **i3 Mega's stock USB cable** (USB-B → USB-A) into the
   powered USB hub (mandatory on Pi 1 B+ and Pi Zero 2 W; optional on
   Pi 4/5).
3. Plug the **dPette's stock USB cable** (microUSB → USB-A) into the
   same powered hub.
4. Power the Pi from a dedicated 5 V brick *or*, if you're confident
   in your PSU, a buck regulator off the printer's 24 V → 5 V rail.

## Identifying the two serial ports on the Pi

On Linux you get `/dev/ttyUSB0` and `/dev/ttyUSB1` (assignment depends
on plug order — unreliable). Use VID:PID and the chip's serial number
to disambiguate, exactly as on the Mac:

```bash
for d in /dev/ttyUSB*; do
  echo -n "$d: "
  udevadm info --query=property "$d" | grep -E '^(ID_VENDOR_ID|ID_MODEL_ID|ID_SERIAL_SHORT)=' | tr '\n' ' '
  echo
done
```

Then export stable paths via `/dev/serial/by-id/` (these don't shuffle
on reboot or replug):

```bash
ls /dev/serial/by-id/
# Expect two entries; one per USB-UART chip serial number
```

Set in your shell profile or systemd unit:

```bash
export I3MEGA_PORT=/dev/serial/by-id/usb-1a86_USB2.0-Serial-...   # or 10c4_CP2102N_<serial>
export PIPETTE_PORT=/dev/serial/by-id/usb-Silicon_Labs_CP2102_USB_to_UART_Bridge_Controller_<serial>
```

(Real-hardware unit at the time of writing has the i3 Mega on a
**CP2102N** with serial `12495223cab7e7119d56ec82d4b43ea0`, not the
CH340 the older docs assume — see
[issue #18](https://github.com/qte77/i3mega-pipettebot/issues/18).)

## Running

```bash
cd ~/i3mega-pipettebot
uv run tools/preflight.py
uv run examples/showcase_v0_i3_pipette_sim.py
```

The first command confirms ports + firmware on real hardware; the
second runs the v0 demo unchanged on the Pi.

The Pi orchestrates both devices over USB. The laptop is no longer
required after the initial flash.

### Optional: systemd unit for auto-start

Drop in `/etc/systemd/system/pipettebot.service`:

```ini
[Unit]
Description=pipettebot showcase
After=network-online.target
Wants=network-online.target

[Service]
Type=simple
User=pi
WorkingDirectory=/home/pi/i3mega-pipettebot
Environment=I3MEGA_PORT=/dev/serial/by-id/...
Environment=PIPETTE_PORT=/dev/serial/by-id/...
ExecStart=/home/pi/.local/bin/uv run examples/showcase_v0_i3_pipette_sim.py
Restart=no

[Install]
WantedBy=multi-user.target
```

Then `sudo systemctl enable --now pipettebot` runs it on boot. For v0
you almost certainly don't want auto-start of physical motion — keep
this disabled and trigger runs manually over SSH until safety
interlocks land (see [issue #11](https://github.com/qte77/i3mega-pipettebot/issues/11)
— soft-limit and crash-guard module).

## What this **doesn't** unlock

- **SD-card autonomy** — Marlin still doesn't know how to talk to the
  dPette. Path 2 just moves the orchestrator from your laptop to the
  Pi. To run a `.gcode` file off the printer's SD card and have it
  pipette, you need **Path 3** (`M820` pass-through, UART tap on the
  dPette, level-shifter PCB, Marlin firmware patch). Tracked under
  the `firmware` label and ADR [#6](https://github.com/qte77/i3mega-pipettebot/issues/6).
- **No PC at all** — you still want a laptop or workstation to SSH in
  for editing, debugging, and triggering runs. The Pi is the
  *runtime* host, not a development environment.
- **Hot-swap dPette** — same standby/connectable button-press quirk
  applies (see [`hardware.md`](hardware.md)). The Pi is just a
  smaller laptop.

## Path from DRAFT to confirmed

No SBC bring-up issue is open yet; the previous
`AGENT_REQUESTS.md` backlog was retired when that file became an
agent-to-human communication channel. File new issues under the
`hardware` label for each unconfirmed item (Pi model choice, BOM,
mount STL, wiring, systemd unit, headless bring-up validation) before
acting on them.

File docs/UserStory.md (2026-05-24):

---
title: "User personas, workflows, and scope"
status: "DRAFT"
updated: "2026-05-17"
---

User personas and the workflows they need to succeed. This file informs
scope decisions and acceptance criteria; it does not replace [open
issues](https://github.com/qte77/i3mega-pipettebot/issues) (the source
of truth for specific actionable work).

## Personas

### 1. Resource-constrained researcher

**Profile.** PhD student, postdoc, or PI in a wet lab with a tight
budget. Repetitive pipetting (gradient prep, plate fills, dilutions,
master-mix distribution) eats hours but doesn't justify an Opentrons
OT-2 ($15,950+) or a Hamilton/Beckman robot ($30k+). Comfortable with
Python; not with custom firmware.

**Has.** An Anycubic i3 Mega (or willing to buy one used for ~$200),
basic lab supplies (96-well plates, disposable tips, reservoirs), a
DLAB dPette electronic pipette.

**Wants.**

- Reproducible aspirate/dispense across a 96-well plate.
- Programmable per-cycle volume (calibration curves, gradients).
- Disposable tips — no carryover between samples.
- A Python control surface; the protocol is just a script.

**Acceptance criteria.**

- `make setup_dev` runs to green on Linux/macOS without root.
- `uv run tools/preflight.py` discovers both i3 Mega and dPette ports.
- `examples/showcase_v0_full_pipettebot.py` runs end-to-end on hardware.
- A TOML profile in `examples/profiles/` drives cycle count + per-cycle
  volumes; `PIPETTE_PROFILE=<file>` is the only env var that needs to
  change to vary a run.

### 2. Maker / educator

**Profile.** Workshop instructor, biohacker, undergraduate course
running a "DIY lab automation" module. Wants a reproducible build that
can be replicated cheaply by every student.

**Has.** Time, a 3D printer (the i3 Mega itself or a second printer),
willingness to print custom mounts.

**Wants.**

- Step-by-step build guide from hardware to first plate fill.
- Printable parts that work on a **stock** i3 Mega (no firmware
  changes, no carriage rewiring beyond removing the hot end).
- Sane safety story: no risk of bricking the printer or driving the
  nozzle into the bed.

**Acceptance criteria.**

- [`docs/hardware.md`](hardware.md) covers cabling, port discovery
  (CH340 vs CP2102), and the Marlin firmware probe.
- [`docs/calibration.md`](calibration.md) walks through the well-A1
  origin procedure and the 9 mm pitch check.
- [`docs/3d-parts.md`](3d-parts.md) documents the CAD pipeline, payload
  budget (`< 300 g`), and slicer printability gate.
- `tools/cad/` parts pass `make check_prints` without overhang/bridge
  warnings.
- The v0 path uses stock Marlin only.

### 3. Open-source contributor

**Profile.** Developer wanting to extend the project — new pipette
models, deck calibration, firmware integration, alternate gantries.
Cares about clean architecture, test coverage, and well-defined
extension points.

**Has.** Git, Python ≥3.11, a working dev environment.

**Wants.**

- Clear separation: gantry layer (G-code) vs pipette layer (6-byte
  serial) vs orchestrator (`PipetteBot`).
- Mocked-serial test fixtures so CI doesn't need hardware.
- Defined places to add modules: the four-module library convention
  (`gantry`, `bot`, `profiles`, `__init__`) plus `examples/` for
  hardware demos and `tools/` for diagnostics.
- Decision-record discipline for architectural changes.

**Acceptance criteria.**

- `make validate` (ruff format/check, mypy strict, pytest mocked) is
  green on every PR.
- [`AGENTS.md`](../AGENTS.md) documents agent rules and the decision
  framework.
- [`docs/adr/`](adr/) captures architectural decisions; new ADRs
  follow `NNNN-<slug>.md`.
- New ops on `src/pipettebot/bot.py::PipetteBot` ship with matching
  cases in `tests/test_bot.py` using `FakeSerial` / `FakePipette`.
- [`AGENT_REQUESTS.md`](../AGENT_REQUESTS.md) is for short-term
  agent-to-human hand-offs only; actionable work lives in GitHub issues.

## Workflows

The end-to-end paths the project must support:

| Workflow | Driver | Doc |
|---|---|---|
| Bring-up — connect both devices, mocked tests pass | [README Quickstart](../README.md#quickstart) | — |
| Hardware probe — any G-code firmware + dPette detected | `tools/preflight.py` | [docs/hardware.md](hardware.md) |
| Well-A1 calibration — measure deck zero, set constants | `tools/gantry_repl.py` | [docs/calibration.md](calibration.md) |
| First plate fill (i3 Mega) | `examples/showcase_v0_i3_full_pipettebot.py` | [docs/deck-layout.md](deck-layout.md) |
| A30 liquid-handling demo (Smartto firmware, polled-Z home) | `examples/showcase_v0_a30_liquid_handling.py` | [docs/research/gantry-firmware-alternatives.md](research/gantry-firmware-alternatives.md) |
| Custom protocol — TOML profile, vary cycles + volumes | `PIPETTE_PROFILE=…` | [examples/experiment_profiles/](../examples/experiment_profiles/) |
| Print a custom part | `make render_all` | [docs/3d-parts.md](3d-parts.md) |
| Deploy on a Single-Board Computer | `tools/setup_pi.sh` | [docs/sbc-deployment.md](sbc-deployment.md) |

## Out of scope (v0)

- **Deck calibration library** — the caller passes raw `(x, y, z)`.
- **Software soft-limit enforcement** — coordinates are untrusted; the
  i3 Mega will happily drive the nozzle into the bed if asked.
- **Firmware modifications** — stock Marlin only. Stage 1+ firmware
  work is tracked in [open issues](https://github.com/qte77/i3mega-pipettebot/issues)
  and must not be merged to `main` without an ADR.
- **Multi-deck / multi-plate workflows** — single deck per session.
- **GUI** — Python API only.

These bounds protect v0's "ships in a weekend" property. Removing any
of them is an architectural decision and needs an ADR.

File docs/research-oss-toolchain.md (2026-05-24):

---
title: "OSS toolchain research — firmware, slicers, alternatives"
status: "DRAFT"
updated: "2026-05-17"
owner: "qte77"
---

Research-grade reference for the OSS components this project depends on
(firmware + slicer + host tooling), the upstream-fork lineage of each,
and credible OSS alternatives if any dependency stalls. Sits orthogonal
to the operational docs:

- [`marlin-commands.md`](marlin-commands.md) — how to drive Marlin today.
- [`hardware.md`](hardware.md) — how to wire the printer and pipette.
- This doc — what these components are, who maintains them, and what
  to switch to if they stop being maintained.

Audience: anyone making a "should we keep / replace / fork X" call,
or auditing the project for OSS-license compatibility before publishing
a derived work.

Licenses below are as observed on each project's canonical (first-party)
repository on the `updated` date in the frontmatter — re-verify on the
upstream repo before relying on any of them for legal purposes.

## Snapshot — what runs today

| Component | What we use | License | Upstream / 1p URL |
|---|---|---|---|
| Motion firmware | MARLIN-AI3M v1.4.6 (1.1.9 base) | GPL-3.0 | <https://github.com/davidramiro/Marlin-AI3M> |
| Motion firmware (parent) | Marlin 1.1.x | GPL-3.0 | <https://marlinfw.org/> |
| Slicer (primary) | OrcaSlicer | AGPL-3.0 | <https://github.com/SoftFever/OrcaSlicer> |
| Slicer (fallback) | PrusaSlicer | AGPL-3.0 | <https://github.com/prusa3d/PrusaSlicer> |
| Pipette driver | dpette-usb-driver | (own repo) | <https://github.com/Lambda-Biolab/dpette-usb-driver> |
| CAD | build123d | Apache-2.0 | <https://github.com/gumyr/build123d> |
| Host orchestrator | pipettebot (this repo) | (own repo) | <https://github.com/qte77/i3mega-pipettebot> |

Every entry above is OSS by intent — no closed-source link in the v0
stack. The "Future-proofing posture" section documents which components
are must-stay-OSS vs. OK-to-swap.

## The RepRap heritage

The entire stack above descends from the **RepRap project** (2005-),
started by Adrian Bowyer at the University of Bath as a self-replicating
desktop machine designed to be open by construction. Reprap.org is the
canonical wiki and project home:

- <https://reprap.org/wiki/Main_Page> — project home
- <https://reprap.org/wiki/Slicer> — survey of OSS slicers in the RepRap lineage

"reprap.com" exists as a UK reseller and partial wiki mirror — for
canonical project references always use **reprap.org**.

Lineage of the components we actually run:

```text
RepRap project (2005-)               https://reprap.org/
  Adrian Bowyer, Univ. of Bath       open hardware + software lineage
  |
  +-- Sprinter firmware (2011)       [archived]
  |     |
  |     +-- Marlin (2011-)           https://github.com/MarlinFirmware/Marlin
  |           Erik van der Zalm      GPL-3.0
  |           + community            https://marlinfw.org/
  |           |
  |           +-- Anycubic stock Marlin 1.4.x   (closed factory build, light mods)
  |           |
  |           +-- MARLIN-AI3M v1.4.6 (1.1.9)    https://github.com/davidramiro/Marlin-AI3M
  |                                              davidramiro, GPL-3.0
  |
  +-- Slic3r (2011-)                 https://github.com/slic3r/Slic3r
  |     Alessandro Ranellucci        AGPL-3.0
  |     |
  |     +-- PrusaSlicer (2016-)      https://github.com/prusa3d/PrusaSlicer
  |           Prusa Research         AGPL-3.0
  |           |
  |           +-- SuperSlicer        https://github.com/supermerill/SuperSlicer
  |           |     supermerill      AGPL-3.0
  |           |
  |           +-- Bambu Studio       (Bambu Lab fork of PrusaSlicer)
  |                 |
  |                 +-- OrcaSlicer   https://github.com/SoftFever/OrcaSlicer
  |                       SoftFever  AGPL-3.0
  |
  +-- RepRapPro Slicer (Java)        https://github.com/holgero/RepRapProSlicer
        holgero, GPL-family          https://reprap.org/wiki/RepRapPro_Slicer
        independent of Slic3r lineage
```

Why this matters: the GPL/AGPL anchor at every node means any firmware
patch we ship (e.g. the Stage 1 `M820` tap, see
[`sbc-deployment.md`](sbc-deployment.md) "What this doesn't unlock")
is a derivative work that must be released under the same license. The
project is positioned to honor that.

## Marlin firmware

Marlin is the motion brain on the i3 Mega. We use the community
**MARLIN-AI3M** variant specifically.

### Why MARLIN-AI3M, not stock or upstream

| Variant | Why we don't use it | Why MARLIN-AI3M wins |
|---|---|---|
| Anycubic stock 1.4.x | Closed-ish factory build; weak community; EEPROM layout has drifted across factory revs.  | n/a |
| Upstream Marlin 2.x | Anycubic config + Trigorilla pin mapping isn't in the box; significant porting cost. | n/a |
| MARLIN-AI3M | n/a | AI3M config in-tree; active community; EEPROM stable; Z probe + thermal-runaway already tuned for AI3M hardware. |

In v0 we run stock MARLIN-AI3M without modifications (see
[`hardware.md`](hardware.md)). Choice of variant matters for **future**
firmware work (Stage 1+), not for the current host-orchestrated workflow.

### Firmware alternatives worth tracking

| Alternative | License  | 1p URL | When to consider |
|---|---|---|---|
| Klipper | GPL-3.0  | <https://www.klipper3d.org/> | Host-side motion planner — offloads compute from the ATmega2560. Input shaping, pressure advance, richer macros. Needs an always-on host (we already have one in Path 2; see [`sbc-deployment.md`](sbc-deployment.md)). |
| RepRapFirmware | GPL-3.0  | <https://www.reprapfirmware.org/> | Duet3D ecosystem. Only viable if we replace the Trigorilla board entirely (heavy refactor). |
| Smoothieware | GPL-3.0  | <https://smoothieware.org/> | LPC1768-based; doesn't run on the AI3M's AVR. Mainboard swap required. |

For v0 and Stage 1 (firmware patch for `M820` pipette pass-through),
MARLIN-AI3M is the right answer. Klipper becomes interesting if input
shaping or richer macros enter scope.

## Slicers

We use the **OrcaSlicer / PrusaSlicer** pair (`tools/slicer/`) —
OrcaSlicer as primary, PrusaSlicer as fallback, both reading the same
`.ini` profile format from `tools/slicer/profiles/i3mega_*.ini`.

### Why OrcaSlicer + PrusaSlicer

- Shared `.ini` profile format — `tools/slicer/profiles/i3mega_*.ini`
  runs against both. Single source of truth per
  `.claude/rules/slicer-profile-source-of-truth.md`.
- Switching to PrusaSlicer if OrcaSlicer ever stalls is a one-line
  change in `tools/slicer/validate.py`.
- Both AGPL-3.0; license-compatible with our internal posture.

### Slicer alternatives

| Alternative | License | 1p URL | Why we'd switch |
|---|---|---|---|
| SuperSlicer | AGPL-3.0 | <https://github.com/supermerill/SuperSlicer> | Drop-in if PrusaSlicer drifts; same `.ini` format. |
| CuraEngine | AGPL-3.0 | <https://github.com/Ultimaker/CuraEngine> | Standalone engine — useful for slicer-as-library. Different profile format (incompatible with our `.ini`s). |
| RepRapPro Slicer | GPL-family | <https://github.com/holgero/RepRapProSlicer> | Java, independent lineage. Niche; mostly relevant for RepRap-canonical builds. |
| Slic3r (legacy) | AGPL-3.0 | <https://github.com/slic3r/Slic3r> | The ancestor. Still alive but development pace is much slower than the PrusaSlicer fork. |
| reprap.org overview | n/a (wiki) | <https://reprap.org/wiki/Slicer> | Survey of the broader landscape (Skeinforge, KISSlicer, etc.) for reference. |

For the printability gate (overhang / unsupported / bridge scan, per
`.claude/rules/cad-printability-gate.md`) all PrusaSlicer-lineage
slicers behave equivalently — the choice is operational (which one is
on the bench), not technical.

## Future-proofing posture

| Component | Posture | Why |
|---|---|---|
| Marlin family | **Must stay OSS.** GPL-3.0 lineage protected. | We will likely need to patch firmware for the Stage 1 `M820` tap; vendor-lock would block this. |
| Slicer family | **Must stay OSS.** AGPL-3.0 lineage protected. | Print profiles are tuned for the AI3M-with-stripped-head geometry — we need source access to add deck-aware safety checks if we ever go autonomous. |
| dpette-usb-driver | **Must stay OSS.** Our own. | Single source of truth for the dPette 6-byte protocol; bus factor = us. |
| build123d | Can swap if needed. | If build123d stalls, OpenSCAD (<https://openscad.org/>) or CadQuery (<https://github.com/CadQuery/cadquery>) are parametric fallbacks. |
| Host orchestrator | n/a (ours) | n/a |

## Exit strategies

- **MARLIN-AI3M unmaintained** — port AI3M's config to upstream Marlin 2.x; medium effort. If the AVR is also dead, replace the Trigorilla board (SKR Mini / BTT clone) and use upstream Marlin 2.x directly.
- **OrcaSlicer unmaintained** — fall back to PrusaSlicer (already wired up in `tools/slicer/`); zero migration cost. Long-term, SuperSlicer is the next cousin.
- **PrusaSlicer relicensed** — pin to the last AGPL-3.0 release; promote SuperSlicer to primary fallback.
- **Both Slic3r-lineage slicers stall** — CuraEngine plus a custom profile translator. Significant work, but viable.
- **Escape Marlin entirely** — Klipper on the existing Path-2 Pi. Largest refactor; only justified if motion-planning richness becomes a bottleneck.

## Open questions

- dpette-usb-driver license — confirm and pin in the snapshot table once the upstream `LICENSE` is verified.
- Whether to vendor a checkpointed copy of MARLIN-AI3M source at the version we run, alongside `tools/cad/` and `tools/slicer/`, so a future fork-loss doesn't lock us out. Tracked as a future AGENT_REQUESTS.md item if we decide to.

## See also

- [`marlin-commands.md`](marlin-commands.md) — G/M-code reference for the Marlin family
- [`hardware.md`](hardware.md) — physical setup, firmware variant table, M115 sanity check
- [`calibration.md`](calibration.md) — Marlin Z=0 calibration after head removal
- [`3d-parts.md`](3d-parts.md) — CAD pipeline (build123d)
- [`sbc-deployment.md`](sbc-deployment.md) — Path 2 (SBC host), Path 3 (SD-card autonomy via firmware patch)
- [reprap.org wiki — slicer overview](https://reprap.org/wiki/Slicer)
- [reprap.org wiki — RepRapPro Slicer](https://reprap.org/wiki/RepRapPro_Slicer)

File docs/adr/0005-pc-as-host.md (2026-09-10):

# ADR 0005: PC-as-host — no firmware modifications through v0

- **Status:** Accepted
- **Date:** 2026-09-09
- **Scope:** [qte77/i3mega-pipettebot](https://github.com/qte77/i3mega-pipettebot) only

## Context

Every supported gantry (Marlin/AI3M on the i3 Mega, Smartto on the A30)
ships stock. The PC drives motion over USB-serial and drives the dPette
over a second, independent USB-serial link — no wire, tap, or firmware
change connects the two devices to each other. `AGENTS.md` rule 4 already
states this as policy ("No firmware modifications in v0 — stock Marlin
only") without recording why, or what the rejected alternatives were. This
ADR formalizes that decision and lays out the staged path (Stage 1 → 2c)
that stays out of scope until a concrete need forces it.

Pipetting cycles are slow: seconds per gantry move, seconds per
aspirate/dispense. USB-serial round-trip latency (~20–50 ms per command) is
three orders of magnitude below the cycle time, so there is no throughput
or timing pressure pushing control logic onto the printer's own MCU.

## Decision

Stay on **Stage 0** through v0: stock firmware, PC orchestrates both
devices independently, no shared clock or shared bus between them. The
staged escalation path, for reference when a future requirement actually
demands it:

| Stage | Description | Trigger to consider it |
|---|---|---|
| **0 (current)** | Stock Marlin/Smartto, unmodified. PC opens two independent serial links (gantry + dPette) and sequences both from Python. | — (default; this ADR keeps v0 here) |
| **1** | `Configuration.h` patch only — e.g. a compiled-in feedrate/limit tuned for the removed print head's mass, no new runtime behavior. Still two independent links; PC still sequences. | A liquid-handling-relevant motion parameter can't be set at runtime (`M203`/`M201`/`M204`/`M205`, per [ADR 0003](./0003-motion-profile-bundled-constants.md)) and has no G-code equivalent. |
| **2a** | Pass-through M-code (custom `M820`-class command) forwarded from Marlin to the dPette over a UART tap. Requires a level-shifter (dPette UART is not 5V-tolerant against the printer board) and a firmware patch to relay bytes. | Round-trip latency between gantry and pipette actually matters — not observed at v0's cycle times. |
| **2b** | Embedded dPette state machine inside Marlin: pipetting commands become G-code the printer executes standalone, enabling headless SD-card runs with no PC in the loop. | A headless/untethered run mode becomes a real requirement (e.g. field deployment without a laptop). |
| **2c** | Motion-planner-synchronous pipetting — aspirate/dispense timed against the stepper planner for sub-50 ms sync. | Probably never needed for disposable-tip, gravity-assisted liquid handling; listed for completeness only. |

Each stage is strictly additive to the one before it and is its own future
ADR + `docs/research/` entry if pursued — this ADR does not pre-approve
any of Stage 1+, it only records where the line currently sits and why.

### Alternatives considered

| Alternative | Why rejected |
|---|---|
| **Stage 1 now** (compile-time Marlin config patch) | No current parameter needs it; every liquid-handling-relevant setting (`MOTION_PROFILE`'s M203/M201/M204/M205 bootstrap) is already runtime-settable over G-code. Patching firmware for a parameter that G-code already reaches would add a build/flash step for zero behavioral gain. |
| **Stage 2a now** (UART pass-through) | Requires new hardware (level-shifter) and a firmware fork per printer family (Marlin and Smartto would each need their own patch) for a latency problem that doesn't exist at pipetting-cycle timescales. |
| **Single MCU driving both gantry and pipette from one firmware image** | Would require reverse-engineering the dPette's control loop into Marlin/Smartto (well beyond a pass-through) and abandons `_Pipette`-Protocol pipette-agnosticism (`AGENTS.md` decision framework) — a new pipette model would need its own firmware fork instead of just a new driver class. |

## Consequences

### Pros

- **Zero firmware risk.** Stock firmware means no bricked boards, no
  per-printer-family firmware fork to maintain, and full compatibility
  with community Marlin/Smartto updates.
- **Two independent serial links stay independently testable.** The
  existing `FakeSerial`/`FakePipette` test doubles (`tests/conftest.py`)
  model this directly — nothing about Stage 0 requires hardware-in-loop
  testing infrastructure Stage 2 would need.
- **`_Pipette` Protocol stays firmware-agnostic.** Swapping pipette
  hardware only ever means a new driver behind the Protocol, never a
  firmware change.

### Cons

- **No headless/untethered run mode.** A PC (or SBC — see
  [`docs/sbc-deployment.md`](../sbc-deployment.md)) must be present and
  running for every pipetting run through v0.
- **Round-trip latency is paid on every command**, currently
  inconsequential but a real cost if per-command overhead ever needs to
  drop below tens of milliseconds.

### Neutral

- **Stage 1+ work is fully deferred, not blocked.** `AGENT_REQUESTS.md`
  and issues #7 (Marlin config patch) and #9 (tip-eject mechanism) already
  track Stage 1/2a candidates; per `AGENTS.md` rule 4 they require their
  own ADR before merging to `main`, which this ADR does not preempt.

## Out of scope

- **Choosing between Stage 2a/2b/2c** — each needs its own bring-up and
  ADR if a trigger condition above is actually met.
- **SBC-vs-PC as the host** — orthogonal to this decision; either can run
  the same Stage-0 two-link orchestration (see
  [`docs/sbc-deployment.md`](../sbc-deployment.md)).

## References

- `AGENTS.md` rule 4 — "No firmware modifications in v0. Stock Marlin
  only." This ADR is that rule's rationale record.
- Issue #6 — original request to document this decision.
- Issues #7, #9 — Stage 1/2a candidates, gated on this ADR existing.
- [ADR 0003](./0003-motion-profile-bundled-constants.md),
  [ADR 0004](./0004-printer-firmware-policy-and-safe-home.md) — sibling
  ADRs for the runtime-tunable motion path this decision keeps in Python,
  not firmware.

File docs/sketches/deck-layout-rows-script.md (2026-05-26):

---
title: "Deck layout — ASCII sketch from showcase_v0_i3_full_pipettebot_rows.py"
status: "DRAFT"
updated: "2026-05-17"
owner: "qte77"
---

ASCII top-down view derived from the constants in
[`examples/showcase_v0_i3_full_pipettebot_rows.py`](../../examples/showcase_v0_i3_full_pipettebot_rows.py).
Captures the geometry the row-tour script actually drives — anchor for
the eventual SVG version (tracked in the visualization-tool follow-up
issue).

i3 Mega bed = 210 × 210 mm. Y convention: Y=0 BACK, Y=220 FRONT
(measured envelope; differs from the older Y=250 figure in some doc
references — verify before relying on `MAX_NUM_CYCLES`-bound values).

## Top-down view

```text
                  ^ FRONT (operator side, Y=high)
       +------------------------------------------------+
Y=220  |                              [tip box row 12]  |  <- bed Y-max
       |                              | (Y=156+9*11=255 |     (warning: row 12 is
       |                              | -- WARNING:     |      outside Y=220 envelope!)
       |                              | outside bed)    |
       |                                                |
Y=210  |                              [tip box row 7]   |  (X=171, Y=210)
       |                              | rows step +9    |
Y=190  |  [bar] release approach (X=10)  |              |  bar: X=5, Y=190, Z=190
       |       engage (X=5, Y=190)        |             |  (oriented along Y)
Y=178  |                                                |
       |       [96-well row 12 max] (X=51, Y=178)       |
       |                                  |             |
Y=156  |       (plate footprint           [tip box row 1] (X=171, Y=156)
       |        X=51..~123,               |             |  rows step +9
       |        8 channels x 9mm)         |             |
Y=130  |                                  [reservoir    |  (X=171, Y=130)
       |                                  | transit Y]  |  (clear of tip-box edge)
Y=100  |                                  [reservoir    |  (X=171, Y=100)
       |                                  | aspirate]   |
Y=79   |       [96-well row 1] (X=51, Y=79)             |  start of dispense ladder
       |                                                |
       |                                                |
Y=10   |  [PARK_FINAL] (X=10, Y=10)                     |
Y=0    [HOME] (X=0, Y=0)                                |
       +------------------------------------------------+
       <- X=0    X=5            X=51..~123       X=171  X=210 ->
        (X-min)                                          (X-max)
                  v BACK (Y=0)
```

## Bar side view (X-Z, operator's perspective)

The release bar is a horizontal rod oriented along the Y axis.
Looking from the front (operator), Z up, X left-to-right:

```text
   Z ^                                                       (looking from FRONT, along -Y)
   ^
220 |                                                         <- bed Y-max (envelope edge)
    |                                                          (bar oriented along Y; cross-section here)
190 |  *  <- BAR cross-section (X=5, Z=190)
    |  |
    |  |     +----------------------------+
    |  |     |  dPette body (X=171 +/-~8, |
    |  |     |   Z extending ~280 mm      |
    |  |     |   below carriage when      |
    |  |     |   loaded with tips)        |
    |  |     |                            |
 98 |  *  <- carriage Marlin Z when hook engages bar
    |
  0 | ----------------------------------------------------  <- deck surface
    +----------------------------------------------------> X
      X=0  X=5            X=51                X=171  X=210
      |    bar             96-well            reservoir +  X-max
      HOME                 plate              tip box      frame
      <- LEFT (operator's left)              (operator's right) ->
```

## Discrepancies to verify before refreshing the doc

These are flagged from user-reported measurements vs script constants
— a calibration pass is queued as a follow-up:

1. **`RELEASE_BAR_X` / `RELEASE_BAR_Y`** were 0 / 220; corrected to 5 / 190
   in this PR per measured fixture. Other scripts using a release bar
   (`showcase_v0_tip_pickup_release.py`) may have similar drift —
   verify before running.
2. **Bed Y-max = 220**, not 250 (per user). The rows script's
   bed-range warning currently says "cycles 11-12 push past Y=250";
   real envelope means cycles 8+ are out (Y=156+9*7=219). Worth a
   `MAX_NUM_CYCLES` revisit (currently 12).
3. **Bar Z ≈ 190** vs the script's `RELEASE_ENGAGE_Z = 98`. Both can
   be true — the engagement Z is the gantry Marlin Z when the hook is
   under the bar; the bar's physical Z is 190 (hook + handle geometry
   bridges the ~92 mm gap). Worth a docstring clarification on the
   relationship.

## Key spatial relationships

- **X separation** between 96-well plate (X=51, channels extend to
  ~X=123) and tip-box / reservoir (X=171) gives ~50 mm clearance — no
  XY collision possible at travel altitude.
- **Y overlap** between tip box (Y=156..255) and plate (Y=79..178) in
  the Y=156..178 zone is OK because they're at different X.
- **Reservoir at Y=100** is between plate (max Y=178) and tip box (min
  Y=156), at the same X=171 as the tip box. The `_aspirate` helper
  does an intermediate `Y=130` move to clear the tip-box footprint
  before diving.
- **Release bar at Y=190** is between the 96-well plate and tip box
  rows, at the leftmost X. Approach at X=10 then slide to X=5 for
  engagement.

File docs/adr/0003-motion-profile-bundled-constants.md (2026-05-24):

# ADR 0003: Motion profile factors as bundled Python constants + `MOTION_PROFILE` env selector

- **Status:** Accepted
- **Date:** 2026-05-17
- **Scope:** [qte77/i3mega-pipettebot](https://github.com/qte77/i3mega-pipettebot) only

## Context

PR #113 shipped a unified XYZ liquid-handling motion profile across all six
gantry-using `examples/*.py` scripts in their bootstraps, with the four
M-codes (`M203` / `M201` / `M204` / `M205`) hardcoded inline in each script.

Hardware DRY-RUN feedback surfaced two issues:
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

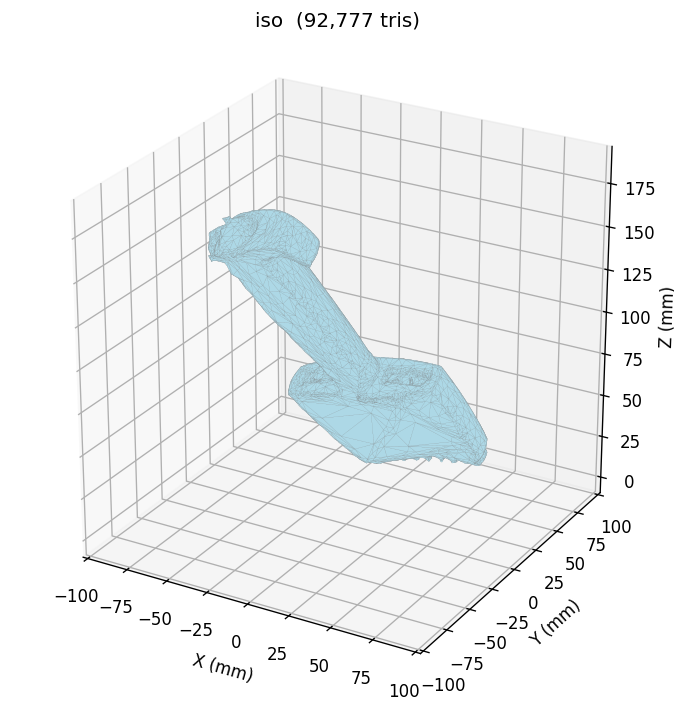
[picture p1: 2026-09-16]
hardware/3d-scan/renders/scan_iso.png

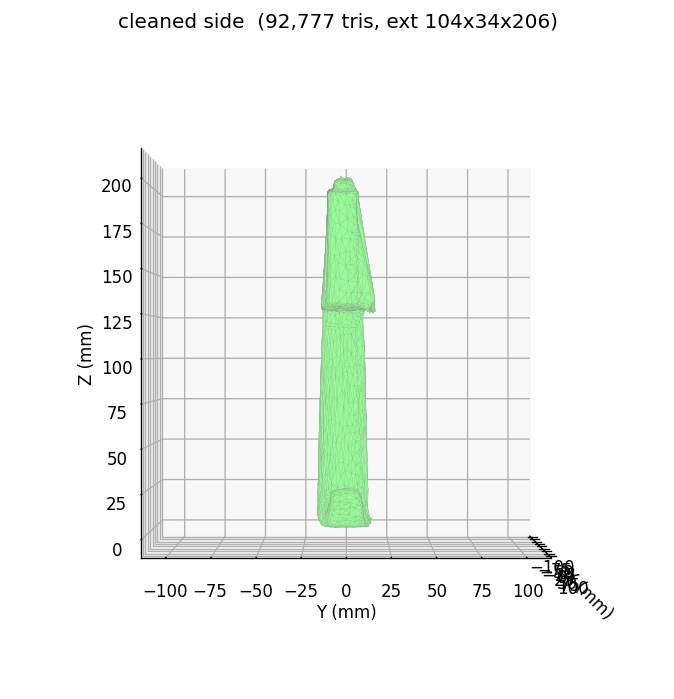
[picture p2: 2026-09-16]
hardware/3d-scan/renders/cleaned_side.png

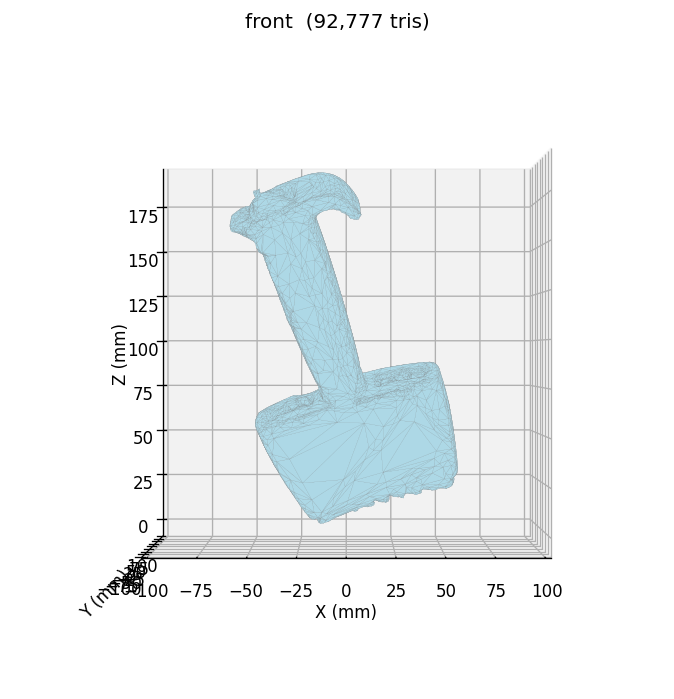
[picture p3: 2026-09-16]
hardware/3d-scan/renders/scan_front.png

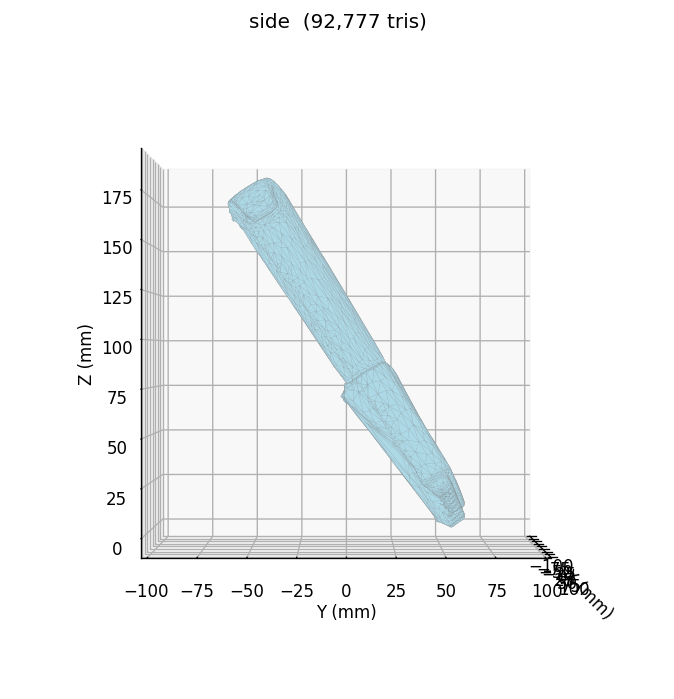
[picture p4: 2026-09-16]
hardware/3d-scan/renders/scan_side.png

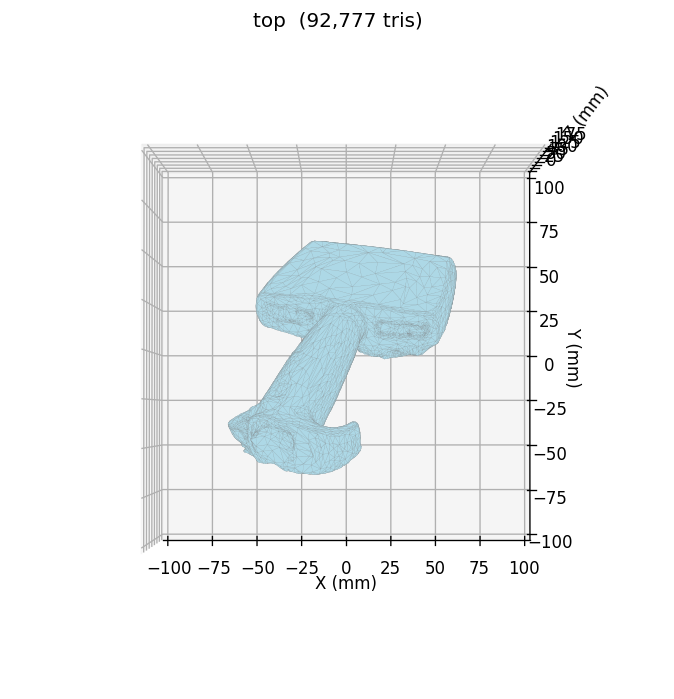
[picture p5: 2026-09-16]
hardware/3d-scan/renders/scan_top.png

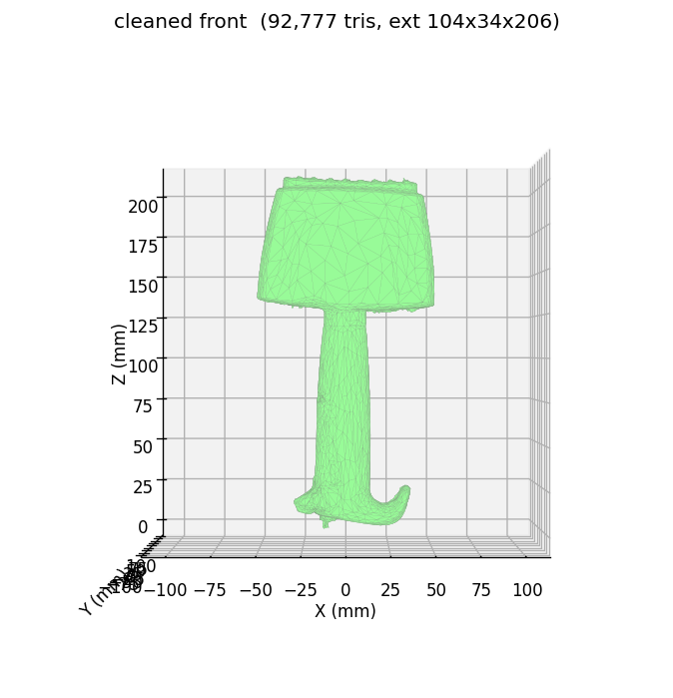
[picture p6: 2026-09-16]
hardware/3d-scan/renders/cleaned_front.png

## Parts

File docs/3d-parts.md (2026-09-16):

---
title: "3D parts: design rationale + labware reference"
status: "DRAFT"
updated: "2026-05-17"
owner: "lambda biolab"
---

Engineering reference for the parts under `tools/cad/`. The pipeline
itself (build123d → STL/SVG → OrcaSlicer printability gate) is described
in [AGENTS.md](../AGENTS.md) "3D Parts Pipeline" — this doc covers the
**why** behind the geometry: payload budget, Z envelope, labware standards.

Audience: anyone editing a `tools/cad/<area>/*.py` script and needing
to know what constraints the design must satisfy.

## Payload budget

> **Canonical rule: total carriage payload (mount + pipette + tips)
> must stay below 300 g.**

The stock Anycubic i3 Mega (AI3M) direct-drive carriage starts losing
steps under XY acceleration once payload exceeds ~300 g (empirical;
varies with belt tension and acceleration setting). All carriage-mounted
designs are sized against this single number.

Worked example for the dPette+ 8-channel target:

```text
budget   < 300 g
pipette  = 250 g  (dPette+ 8-channel; see hardware.md for source)
tips × 8 ≈   3 g  (300 µL polypropylene)
mount    < 300 − 250 − 3 = ~47 g
```

→ ~38 cc PLA volume budget for the mount (density 1.24 g/cc).
Practical implication: thin walls (1.5–2 mm), gyroid infill ≤ 20 %,
ribbed/triangulated stalks instead of solid blocks.

`.claude/rules/i3-carriage-payload-budget.md` enforces a `# Mass:`
annotation on every `build_*()` in `tools/cad/i3/`. Hypothesis tests
asserting `mount + pipette + tips < 300` are tracked in
[#42](https://github.com/qte77/i3mega-pipettebot/issues/42).

## Z envelope

i3 Mega is a bed-slinger: the **carriage moves only X+Z** (no Y), the
**bed moves Y**. The X-frame top sits 25 mm behind the carriage front
face and is therefore in a different spatial Y plane — it can never
collide with the pipette regardless of axis motion.

Vertical math, after stripping the print head:

```text
carriage face → bed (at Z_axis = 0)            : 19 mm
bed → X-frame top (full Z envelope)            : 290 mm
pipette tip → top (with 50 mm tip mounted)     : 280 mm
lower clamp → tip end                          : 150 mm
```

The 150 mm = 100 mm (clamp to bare body bottom) + 50 mm (tip extending
below the body).

Lower clamp sits at the carriage face level, so:

```text
tip Z = carriage_face_Z - 150 mm
```

For tip-at-bed (Z=0): `carriage_face_Z = 150 mm` → `Z_axis ≈ 131 mm`
(carriage face is 19 mm above bed at Z_axis=0).

**Usable Z range ≈ Z_axis 136 mm → 186 mm (~50 mm of pipetting travel)**
— enough for plate-to-plate work on labware up to ~25 mm tall. After
mount install, a tip-touch-off recalibration sets the new Z origin
(see [calibration.md](calibration.md)).

The pipette top can rise *above* the X-frame top in Z because they sit
in different Y planes — no upper Z bound from the X-frame. The dPette+
360° rotatable top adds extra angular clearance if needed.

## Mount geometry decisions

Two-clamp design:

- **Lower clamp** at carriage face level — split-bore 75 × 16 mm
  around the dPette+ body, above the ejector lever. Maximum mechanical
  stability (zero vertical lever arm to the screws).
- **Upper clamp** ≈ 100 mm above carriage face — Ø 27 mm round around
  the upper barrel. Prevents tilt under XY acceleration. Attachment is
  a bolted two-piece cap (production); a glue/friction-fit variant was
  tried and abandoned mid-iteration — see
  [#75](https://github.com/qte77/i3mega-pipettebot/issues/75) and
  `tools/cad/i3/carriage_dpette_mount_frictionfit.py`'s module
  docstring. #75 is only half-resolved: bolts were reintroduced, but
  its bore re-measurement request (down to Ø24.5 mm) was not — the
  bolted design still uses the original Ø27 mm bore.

Forward projection: the lower clamp sits 15–25 mm in front (-Y) of the
carriage face so the pipette body clears the X-frame in spatial Y.
Constant in code (midpoint of the range, single source of truth):
`tools/cad/i3/carriage_dpette_mount.py::CLAMP_FORWARD_OFFSET_MM = 22.0`.

Open work: real geometry blocked on carriage measurements
([#40](https://github.com/qte77/i3mega-pipettebot/issues/40));
barrel-bore primitives extracted into a reusable module
([#41](https://github.com/qte77/i3mega-pipettebot/issues/41));
real scan vendored from so101
([#43](https://github.com/qte77/i3mega-pipettebot/issues/43)).

## SBS labware reference

Every `tools/cad/labware/` part conforms to the **SBS / ANSI-SLAS 2004-1
microplate footprint** (127.76 × 85.48 mm). This makes our holders
compatible with off-the-shelf labware from any manufacturer that
follows the standard.

| Labware | Footprint | Height | Notes |
|---|---|---|---|
| 96-well plate | 127.76 × 85.48 mm | ~14.35 mm | Modelled by `plate_holder.py` |
| Tip rack (96-tip variant) | ~122 × 80 mm | ~50 mm with tips | Modelled by `tip_rack_holder.py` |
| Reservoir, single-well V-bottom (100 mL) | 127.76 × 85.48 mm | ~30–40 mm | Bulk reagent for 8-channel — to be modelled |
| Reservoir, 8-channel divided (25 mL) | 127.76 × 85.48 mm | ~30 mm | Per-channel reagents — to be modelled |
| 8-channel-specific reservoir (e.g. MTC Bio ASPIR-8) | narrower than SBS | ~25 mm | Conserves bench space; optional |

Channel pitch for the dPette+ 8-channel matches SBS rows: **9.0 mm
centre-to-centre**, 8 channels span 63 mm.

Bed fixation of labware: deferred. v0 plan is binder clips at the
corners; a bed-adapter plate that snaps holders into known positions is
on the backlog.

## References

- [MTC Bio ASPIR-8 reagent reservoirs](https://www.thomassci.com/scientific-supplies/8-Channel-Reagent-Reservoirs) — 8-channel-specific reservoir, narrower than SBS
- [Multichannel pipette reservoir overview (Thomas Scientific)](https://www.thomassci.com/scientific-supplies/Multichannel-Pipette-Reservoir) — full SBS-footprint catalogue

dPette+ 8-channel product page is in [`hardware.md`](hardware.md).

## Open issues

| # | Topic |
|---|---|
| [#40](https://github.com/qte77/i3mega-pipettebot/issues/40) | Measure AI3M carriage screw pattern |
| [#41](https://github.com/qte77/i3mega-pipettebot/issues/41) | Extract barrel-bore primitives into reusable module |
| [#42](https://github.com/qte77/i3mega-pipettebot/issues/42) | Hypothesis tests for mount payload budget |
| [#43](https://github.com/qte77/i3mega-pipettebot/issues/43) | Vendor real dPette barrel scan |
| [#44](https://github.com/qte77/i3mega-pipettebot/issues/44) | Confirm OrcaSlicer install method |
| [#45](https://github.com/qte77/i3mega-pipettebot/issues/45) | ADR: Arduino host architecture |
| [#75](https://github.com/qte77/i3mega-pipettebot/issues/75) | Upper-clamp cap: bore re-measurement still open (bolts reintroduced; sizing not) |

Note: #40, #41, #42 are closed — left off this table. #43/#44 remain open.

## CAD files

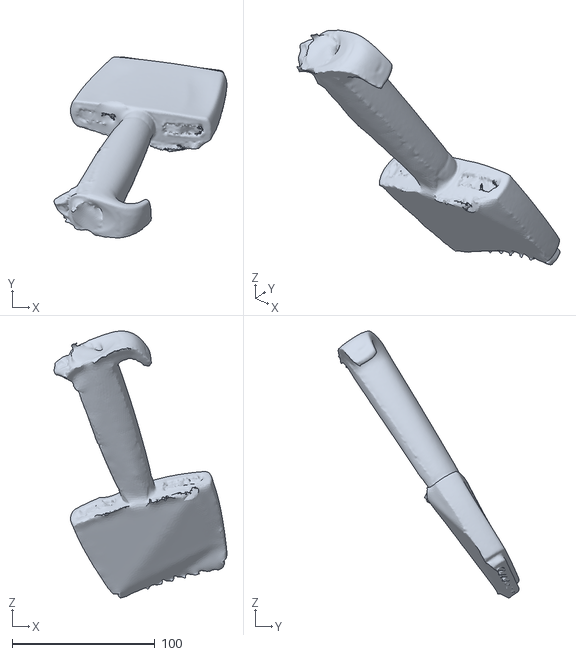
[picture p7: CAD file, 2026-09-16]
hardware/3d-scan/pipette_scan_raw.stl
121.2 x 127.0 x 187.1

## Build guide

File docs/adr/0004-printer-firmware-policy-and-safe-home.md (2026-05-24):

# ADR 0004: Single `PRINTER_PORT` env + policy-driven `safe_home` dispatcher

- **Status:** Accepted
- **Date:** 2026-05-24
- **Scope:** [qte77/i3mega-pipettebot](https://github.com/qte77/i3mega-pipettebot) only

## Context

A30 bring-up (`docs/research/gantry-firmware-alternatives.md`, 2026-05-23
entries) confirmed Smartto v1.xx.58 as a second supported gantry firmware
family. Two operational problems followed from supporting more than one
printer in the same repo:

1. **Per-model port env vars proliferated.** Each new firmware/printer
   pair earned its own alias (`I3MEGA_PORT`, `SMARTTO_PORT`) plus a
   generic fallback (`GANTRY_PORT`). `tools/preflight.py`,
   `tools/gantry_repl.py`, and `tools/gantry_probe.py` each carried a
   private `("I3MEGA_PORT", "SMARTTO_PORT", "GANTRY_PORT")` resolution
   order. A third printer would have multiplied the surface again.
2. **`G28` is unsafe on Smartto/A30 with head removed.** The probe-pin
   variant in stock Smartto firmware drives Z indefinitely; only
   `G28 X Y` + manual `G92 Z0` is safe. Examples that hardcode `G28`
   crash the gantry into the bed when pointed at an A30. The runbook in
   the research log spells out the correct sequence step-by-step, but
   nothing in the library prevents an unsafe call.

The `FirmwarePolicy.home_strategy` field already classified this
(`"full_g28"` for Marlin, `"xy_then_polled_z"` for Smartto,
`"manual_only"` for unknown), but no code consumed it — homing was
implicit `gantry.home()` (== `G28`) at every call site. The classification
was advisory text, not enforcement.

## Decision

### 1. Collapse all port aliases to a single `PRINTER_PORT` env var

`FirmwarePolicy` no longer carries `port_env_aliases`. `devices.py`
exposes a module-level `PRINTER_PORT_ENV = "PRINTER_PORT"` and
`resolve_port(env=os.environ)` reads exactly that name. Firmware family
is identified by `discover()` post-open, not by which env var the
operator chose to set.

`tools/preflight.py --export` prints `export PRINTER_PORT=...`
regardless of the detected family. Operators set one env var; the same
shell session can drive any supported printer.

### 2. Introduce `safe_home(gantry, policy, *, z_min_triggered, ...)` as a free function in `devices.py`

```python
def safe_home(
    gantry: GcodeGantry,
    policy: FirmwarePolicy,
    *,
    z_min_triggered: Callable[[GcodeGantry], bool] = _read_z_min_triggered,
    max_steps: int = 250,
    step_mm: float = 1.0,
    feedrate: int = 300,
) -> None:
```

Branches on `policy.home_strategy`:

- `full_g28` → `gantry.home()` (sends `G28`).
- `xy_then_polled_z` → `G28 X Y` then polled descent: `G91`, loop
  (`G1 Z-step_mm F<feedrate>`, `M400`, `M119`-via-`z_min_triggered`,
  break-on-triggered), `G90`, `G92 Z0`. If `z_min_triggered` returns
  True before the first descend step, the loop is skipped and origin
  is declared immediately. If `max_steps` is exceeded without trigger,
  `G90` is restored (`try`/`finally`) and `RuntimeError` is raised
  without declaring origin. Required on Smartto/A30 builds where
  firmware `G28 Z` dives indefinitely (probe-pin variant ignores the
  working `z_min` switch).
- `manual_only` → raise `RuntimeError`. Operator must home via
  `tools/gantry_repl.py` and set origin by hand.

The default `_read_z_min_triggered` probe sends `M119` and substring-
matches `z_min:TRIGGERED` in the multi-line reply — same logic that
worked for both Smartto and Marlin in the bring-up log. Inject a fake
for tests or to read a different endstop pin.

`GcodeGantry` gained two public methods: `send(line) -> str` (returns
only the terminating `ok` line — for fire-and-forget commands) and
`query(line) -> list[str]` (returns every non-empty reply line including
the `ok` — for commands whose payload matters: `M119`, `M114`, `M115`,
`M503`). The polled descent loop uses `query("M119")` via
`_read_z_min_triggered` to read sensor state.

### Alternatives considered

| Alternative | Why rejected |
|---|---|
| **Two adapter classes (`MarlinGantry` / `SmarttoGantry`) behind a `GantryProtocol`** | Original recommendation in `docs/research/gantry-firmware-alternatives.md` was revised same-session: the two diverge on three fields only (default baud, home strategy, capability metadata). A second class would duplicate `move_to` / `wait_for_moves` for zero behavioral gain. Free function + policy data is the AHA-compliant scope. |
| **Method on `GcodeGantry`: `gantry.home(policy)`** | Requires moving `FirmwarePolicy` from `devices.py` into `gantry.py` (else circular import — `devices.py` already imports from `gantry.py`). Composition-over-coupling preferred: `safe_home` lives in `devices.py` alongside `policy_for()` and `discover()`, where firmware-identity concerns already cluster. |
| **Keep `port_env_aliases` on `FirmwarePolicy` for forward flexibility** | YAGNI. After collapse, every policy held the same single-element tuple `("PRINTER_PORT",)`. The field added indirection without supporting any actual divergence. Re-add if a future firmware genuinely needs a different env name. |
| **Inline the safe-home sequence in each example script** | Duplication smell at three (soon: more) call sites, none of which would consistently emit the correct `G28 X Y` + `G92 Z0` pair. The whole point of `home_strategy` is to centralize this; honoring it requires a central consumer. |
| **Manual operator-confirm Z origin (jog by hand + press Enter)** | Initially shipped — matched the v0 runbook in the research log. Withdrawn post-hardware-test: the A30's Z axis is a stepper-energized leadscrew, so "jog by hand" is not actually possible. The polled descent uses the working inductive `z_min` sensor that `M119` correctly reports (firmware `G28 Z` ignores it, but `M119` reads it fine). |

## Consequences

### Pros

- **One env var across the project.** Operators set `PRINTER_PORT` once;
  `tools/preflight.py --export` produces it; every script, tool, and
  example reads the same name.
- **Unsafe homing is no longer the path of least resistance.**
  `safe_home(gantry, policy_for(discover(port)))` is shorter to type
  than rebuilding the `G28 X Y` / `G92 Z0` pair by hand, so new
  examples will reach for it.
- **`manual_only` policy is now enforceable.** Unknown firmware can
  no longer accidentally receive a `G28` — `safe_home` raises before
  any G-code is written.
- **Callback injection keeps tests pure.** All three branches covered
  with `FakeSerial` + `lambda _: ""` injection; no monkeypatching.

### Cons

- **One-time migration cost for any out-of-tree script** that read
  `I3MEGA_PORT` / `SMARTTO_PORT` / `GANTRY_PORT`. None exist in this
  repo, but the v0.1.0 tag did expose those names in tool docstrings.
  CHANGELOG entry called out as breaking.
- **`safe_home` knows about both `full_g28` and `xy_then_polled_z`.**
  Adding a new home strategy requires editing one function — but that
  was already true of the `home_strategy` field's enum-string design.

### Neutral

- **`GcodeGantry.send()` is now public.** Internal callers were already
  using `_send`; the rename is mechanical. External callers that
  reached for `_send` (none in-repo) should migrate.
- **Existing examples were renamed with an `_i3` infix** to flag them
  as i3-Mega-only (hardcoded 210x210 deck coords + plain `G28`). New
  A30 scripts live alongside under their own naming convention. This is
  the "rename to indicate constraint" alternative to a flag-driven
  generic example, and is consistent with not invoking `safe_home`
  from the legacy scripts in this PR.

## Out of scope

- **Porting the seven `_i3` showcases to use `safe_home`.** They use
  raw serial sends bypassing `GcodeGantry` (the
  `_send` one-line-readline bug, issue #26); porting them needs the
  bug fixed first. Tracked separately.
- **A `BAUD` env var as the printer-agnostic equivalent of
  `PRINTER_PORT`.** Each script still defaults baud per its target;
  the discovered baud (from `pipettebot.devices.discover()`) is
  authoritative when present. Promote to a single env if/when a third
  baud appears.
- **Auto-discovery inside example scripts.** Examples take `PRINTER_PORT`
  explicitly; `tools/preflight.py --export` is the supported discovery
  surface. Implicit discovery in examples would couple every demo to
  the full port-scan logic.

## References

- `docs/research/gantry-firmware-alternatives.md` — 2026-05-23 A30
  bring-up entries; the `xy_then_polled_z` recipe and the architecture
  revision (single class + policy, not two adapter classes) originate
  there.
- `src/pipettebot/devices.py` — `FirmwarePolicy`, `safe_home`,
  `resolve_port`, `PRINTER_PORT_ENV`.
- [ADR 0003](./0003-motion-profile-bundled-constants.md) — sibling
  env-var selector pattern (`MOTION_PROFILE`) this ADR's
  `PRINTER_PORT` aligns with.

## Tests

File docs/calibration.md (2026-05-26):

---
title: "Well-origin calibration"
status: "DRAFT"
updated: "2026-05-07"
owner: "lambda biolab"
---

Every i3 Mega has slightly different X/Y home offsets, and a well plate
is mechanically taped to the bed — there is no idealized origin. Before
running [`examples/showcase_v0_i3_pipette_sim.py`](../examples/showcase_v0_i3_pipette_sim.py)
you must measure where the back and front wells actually are on
**your** build and update the hardcoded constants.

In v0 calibration is a **manual edit-and-rerun** workflow. A proper
deck-frame library with persisted JSON calibration is in
[AGENT_REQUESTS.md](../AGENT_REQUESTS.md) and tracked as a follow-up
issue.

## Pre-requisites

- Hardware setup done — see [`hardware.md`](hardware.md).
- A 96-well plate (SBS footprint, 9 mm well-to-well pitch) physically
  taped to the bed. Long axis (12 columns) parallel to **X**; short axis
  (8 rows) parallel to **Y**. Row A nearest the printer's front.
- A G-code REPL: [pronterface](https://www.pronterface.com/) or any
  terminal that speaks Marlin (e.g. `screen /dev/ttyUSB0 115200`).
- A tip on **channel 1** of the dPette+ 8-channel head (leftmost
  channel — visual reference only, no aspirate yet).
- **Z origin re-calibrated** — see "Post-strip Z re-cal" below.

## Post-strip Z re-cal (dPette mount installed)

"Post-strip" = after the print head + PCB are removed and the dPette
mount is bolted onto the bare carriage (see [`hardware.md`](hardware.md)
"Workspace constraints").

Stock Marlin's Z=0 was calibrated to nozzle-touching-bed. With the
hotend gone, that reference no longer corresponds to anything useful:
the carriage face sits ~19 mm above the bed at Z_axis=0, and the
dPette tip with a 300 µL tip mounted hangs ~150 mm below the carriage
face. See [`3d-parts.md`](3d-parts.md) for the Z-envelope math.

One-shot tip-touch-off procedure:

1. Mount the dPette in the carriage and load a tip on **channel 1**
   (leftmost channel of the 8-channel head).
2. Place a sheet of paper flat on the bed under the tip.
3. Home: `G28`. Read baseline: `M114`.
4. Jog Z down slowly until the tip just kisses the paper — the paper
   should drag with light resistance under the tip:

    ```text
    G91
    G1 Z-5 F600
    G1 Z-1 F300
    G1 Z-0.1 F60
    ...
    G90
    M114
    ```

5. Set this Z as the new origin: `G92 Z0` (live override) and/or
   `M428` (tell Marlin "current position = home for current axes").
   `G92 Z0` is sufficient for v0 since the value isn't persisted across
   power cycles.
6. Lift to a safe travel altitude before any XY motion: `G1 Z40 F1200`.

The tip-touch Z value is the new reference for `WELL_Z` in
`examples/showcase_v0_i3_pipette_sim.py`. Add ~5 mm so the tip doesn't
crash into the well bottom on every cycle.

Re-run this procedure whenever you swap pipettes (single-channel ↔
8-channel) or change the tip volume class — different tips have
different lengths.

## Step-by-step

### 1. Home

```text
G28
```

After homing, Marlin reports `0,0,0` for X/Y and the configured Z
endstop position. **Read this baseline with `M114`** and write it down:

```text
M114
> X:0.00 Y:0.00 Z:0.00 E:0.00 Count X:0 Y:0 Z:0
```

### 2. Position over well A1

Jog X/Y until the dPette tip is **centered over well A1** (the corner
nearest the printer's front-left). Jog in 5 mm steps until close, then
in 1 mm steps for fine alignment.

Pronterface: use the on-screen jog buttons. Manual G-code:

```text
G91         ; relative mode
G1 X10 F2400
G1 X-1 F600  ; fine
...
G90         ; back to absolute
M114        ; record current position
```

Note the X and Y values reported by `M114`. **These are your
`WELL_A1[0]` and `WELL_A1[1]`.**

### 3. Find the dispense Z

This **replaces** the post-strip tip-touch-off Z (which was on the bare
bed). Now you find the Z at which channel 1's tip enters well A1 to a
useful depth.

With X/Y locked over A1, jog Z down slowly until the tip just kisses the
bottom of well A1:

```text
G91
G1 Z-5 F600
G1 Z-1 F300
G1 Z-0.1 F60   ; finest step
...
G90
M114
```

Record this Z. Add a small clearance (~0.5–1 mm) so you do not crash
into the plate on every cycle. **This is your `WELL_A1[2]`.**

Raise to a travel altitude that clears the plate's top edge (typically
plate top + 20 mm; a 14 mm SBS plate → travel Z ≈ plate-bottom Z + 35
mm). The 40 mm default in the showcase script assumes a stock hotend
and **must be re-derived** for the dPette geometry — see
[`3d-parts.md`](3d-parts.md) Z-envelope section.

### 4. Verify the 9 mm pitch on B1

Now translate Y by exactly 9 mm and check that the tip is centered over
well B1:

```text
G91
G1 Y9 F600    ; row B is +Y from row A
G90
M114
```

If the tip is centered over B1, your plate is square. If it is offset,
the plate is rotated relative to X — re-tape and start over from step 2.

`WELL_B1` is `(WELL_A1[0], WELL_A1[1] + 9.0, WELL_A1[2])`.

### 5. Update the showcase script

Open [`examples/showcase_v0_i3_pipette_sim.py`](../examples/showcase_v0_i3_pipette_sim.py)
and replace the constants near the top:

```python
CENTER_X = X_FROM_M114        # was 105.0 (mid-bed default)
BACK_WELL_Y = Y_FROM_M114     # was 180.0
FRONT_WELL_Y = ...            # was 20.0 (or any Y with clear travel)
WELL_Z = Z_FROM_M114          # post-strip Z is in the ~131 mm range, NOT 5
TRAVEL_Z = WELL_Z + 35.0      # plate top + ~20 mm of margin
```

Run [`make validate`](../Makefile) to make sure your edits still type-check
and pass formatting.

### 6. Sanity check

Re-run preflight, then run the showcase with **water in well A1** and an
empty B1:

```bash
uv run tools/preflight.py
uv run examples/showcase_v0_i3_pipette_sim.py
```

The first command confirms ports + firmware before motion.

Watch the first cycle carefully. If anything looks wrong, **kill power
to the printer** before debugging. The PC has no soft-limit enforcement
in v0.

## What is deferred

- A proper `deck.py` with `WellPlate96`, `TipRack`, and named slots
- An origin-probe routine (`G38.2`-style) that auto-finds A1
- Persistence to a JSON file so you do not edit `showcase_v0_i3_pipette_sim.py` every time
- Soft-limit `safety.py` module (`MIN_TRAVEL_Z`, `DISPENSE_Z_OFFSET`)

All tracked in [AGENT_REQUESTS.md](../AGENT_REQUESTS.md) and follow-up
issues.

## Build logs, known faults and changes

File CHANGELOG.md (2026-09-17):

# Changelog

All notable changes to this project will be documented in this file.

<!-- scriv-insert-here -->

## [Unreleased]

## [0.2.0] — 2026-09-17

Third tagged release. Adds an ADR for the firmware-modification escalation
path, Pi 3 B+ deploy infrastructure, motion-profile + deck-layout SVG
visualization with dark-mode theming shared across the CAD and viz
pipelines, a dPette+ 8-channel column-pitch constant, and a substantial
doc/governance sync — on top of the A30/Smartto bring-up and CAD/slicer
pipeline work accumulated below since 0.1.0.

### Changed

- `pipettebot.gantry.open_marlin_port` renamed to `open_gcode_port` (the helper is firmware-agnostic — a Linux baud helper, not a Marlin-protocol thing). The old name is preserved for one release cycle as a one-line alias that emits `DeprecationWarning` on call, so downstream scripts keep working while operators migrate. All in-tree callers (`pipettebot.devices.discover`, `tools/gantry_repl.py`, `tools/gantry_probe.py`, `tools/diagnose_axis.py`, `examples/home_G28_fast.py`) updated to the new name. Both names re-exported from `pipettebot.__init__`.
- **Single `PRINTER_PORT` env across the project.** `FirmwarePolicy.port_env_aliases` field removed; per-model `I3MEGA_PORT` / `SMARTTO_PORT` / generic `GANTRY_PORT` collapsed into one `PRINTER_PORT_ENV` constant in `pipettebot.devices`. Firmware family is identified by `discover()` after open, not by which env var the operator set. `tools/preflight.py --export` emits `export PRINTER_PORT=...` regardless of detected family; `tools/gantry_repl.py` and `tools/gantry_probe.py` read `PRINTER_PORT` only. Existing `_i3` example scripts updated to read `PRINTER_PORT` / `PRINTER_BAUD` in lockstep.
- **Existing showcase scripts renamed with `_i3` infix** (`home_G28_fast_i3`, `showcase_v0_i3_pipette_sim`, `showcase_v0_i3_full_dpette_cycles`, `showcase_v0_i3_full_pipettebot`, `showcase_v0_i3_full_pipettebot_rows`, `showcase_v0_i3_full_plate`, `showcase_v0_i3_tip_pickup_release`). They're hardcoded to i3-Mega deck coords (210×210 bed) and plain `G28`, which would crash Z on Smartto/A30 builds. Same directory now hosts A30 scripts alongside without naming ambiguity.
- **Motion profiles retuned to exact 3x ratio** — SLOW (accel_x/y/z 200/267/67, jerk 1.0/1.67/0.07, accel_default 200) → MID (600/800/200, 3/5/0.2, 600) → FAST (1800/2400/600, 9/15/0.6, 1800). Earlier values had non-uniform spacing (FAST was 1.67x MID on accel_x, 1.5x on accel_y); third/triple around the operator-validated MID anchor makes the per-profile difference obvious on the bench and predictable when tuning per-leg feedrates inside these caps. Accel rounded to integer mm/s² (M201/M204 want integers); jerk to two decimals. ADR 0003 example block + motion_profile.py docstring comparison table both updated to match.
- **`so101-biolab-automation` pinned to a commit SHA** instead of a floating `@main` ref (mirrors the existing `dpette` pin), and `[tool.uv] exclude-newer` bumped forward. Root-cause fix for `main`'s CI (`lint-and-test`) failing on every push for roughly two months: the floating ref bumped its `fastapi`/`numpy` floors past the resolver's cutoff, and this project's `uv.lock` is deliberately gitignored (library project), so every CI run re-resolved from scratch and hit the same failure.
- **`tools/slicer/validate.py`**: now detects PrusaSlicer's silent `"objects outside the print volume"` exit-0 case as a real failure, requires the output file to actually exist before declaring PASS, and forwards `tools/slicer/profiles/*.ini` keys as explicit CLI flags (PrusaSlicer 2.9.4's `--load` silently drops most profile keys).
- **`tools/slicer/profiles/pla_plus_02mm.ini`**: added `first_layer_temperature`, `first_layer_bed_temperature`, and a `start_gcode`/`end_gcode` pair that actually heats the bed before printing (previously the slicer emitted nozzle heat only, and PLA wouldn't stick).
- **`docs/3d-parts.md`**, **`AGENT_LEARNINGS.md`**: cross-referenced issue #75 (upper-clamp cap history) and corrected a stale "Open issues" table that still listed several already-closed issues.

### Added

- **`docs/research/aspirate-monitoring.md`** — append-only research log on aspirate verification (clog / dry-well / volume confirmation) technologies. First entry surveys Hamilton MAD / TADM as the industry reference; verdict for v0 is document-only (the dPette+ nozzle has no exposed sensor port and a bolt-on inline pressure sensor would require dPette+ internal characterization out of scope for v0). Linked from the Deferred section of `docs/roadmap.md` and from the Documentation index in `README.md`.
- **`docs/research/tip-disposal-belt-module.md`** — append-only research log on used-tip disposal mechanisms. First two entries cover the conveyor-belt 3D printer landscape (all commercial belt printers are tilted roll-off; no horizontal-loop product exists at any price; verified vendor list with first-party citations from `3dsourced.com`, `clevercreations.org`, and the `NAK3DDesigns/White-Knight` GitHub repo) and a commodity standalone belt module (~$37–72 BOM, deferred behind firmware-modification gating per AGENTS rule #4). v0 keeps the passive `dpette_tip_release` waste slot. Linked from the Deferred section of `docs/roadmap.md` and from the Documentation index in `README.md`.
- **`docs/research/alternative-pipettes.md`** — append-only research log evaluating candidate pipettes for the `_Pipette` Protocol. First three entries: DLAB dPette+ (supported reference) and 8-channel dPette (candidate, untested, multi cradle already in `parts.json`); Opentrons GEN2 (not viable — proprietary CAN protocol with no public documentation); ac-rad Digital Pipette (out of scope — syringe, not disposable-tip). Linked from the Documentation index in `README.md`.
- **`README.md` related-repositories entry**: added [`xg590/Learn_dPettePlus`](https://github.com/xg590/Learn_dPettePlus) as the intellectual-lineage source for the `dpette-usb-driver` reverse-engineering.
- **`[tool.pyright]` config block in `pyproject.toml`** (#158, by JosefVacha — fixes #156). Points Pyright at the project venv (`.venv`) and `src/` layout so editor / Pylance diagnostics align with `mypy --strict src/`'s view. No CI gate change; `make validate` still runs `mypy --strict src/`. Eliminates the "Import could not be resolved" noise for pytest / hypothesis / pipettebot.devices / serial that surfaced repeatedly during PR #157 work.
- **Signed-commits policy in CONTRIBUTING.md** (#159). Every commit on a PR branch must carry a verified GPG or SSH signature. Squash-merge preserves contributor author attribution on `main` (web-flow signs the squash commit), so the requirement is about source-commit chain-of-custody, not credit. Anticipated follow-up: enable "Require signed commits" in branch-protection settings to enforce mechanically.
- **`pipettebot.devices.safe_home(gantry, policy)` dispatcher** — policy-driven home: `full_g28` (Marlin) sends `G28`; `xy_then_polled_z` (Smartto/A30) runs `G28 X Y` + absolute-mode polled-Z descent + `G92 Z0`; `manual_only` (unknown) raises. Polled descent uses M119 polling between absolute `G1 Z<target>` steps (Smartto's `G91` G1 Z doesn't move; absolute does), `G92 Z<max_travel>` headroom bypasses soft endstops, per-step 0.8 s host sleep prevents Smartto's M400-race from queueing commands ahead of physical motion, and the failure path captures both M119 + M114 for triage. `home_xy=False` skips `G28 X Y` for post-cycle Z-only verification. Hardware-validated on Geeetech A30 + Smartto v1.xx.58.
- **`GcodeGantry.send(line)` and `.query(line)` public methods.** `send` returns just the terminating `ok` line; `query` returns every reply line (multi-line `M119`/`M114`/`M115`/`M503`). Both used by `safe_home`. `.flush_input()` for stale-buffer recovery after long burst sessions.
- **ADR 0004 — Single `PRINTER_PORT` env + policy-driven `safe_home`** documents the alias collapse, alternatives considered (two adapter classes vs. method-on-GcodeGantry vs. free function), and the manual-confirm Z-home approach that was withdrawn after hardware testing (A30's stepper-energized leadscrew can't be jogged by hand).
- **`examples/home_safe_a30.py`** — dedicated A30 home script. Counterpart to `home_G28_fast_i3.py`. Applies motion profile then calls `safe_home`; exits. Verified live: polled descent triggers at the inductive sensor's LED point.
- **`examples/showcase_v0_a30_liquid_handling.py`** — end-to-end A30 liquid-handling demo. Discovery → motion profile → pre-home Z lift (forces fresh descent every run) → `safe_home` → linger at Z=0 → N transfer cycles with split-feedrate dives (`XY_FEED`/`Z_FAST_FEED`/`LIQUID_DIVE_FEED`, `TOUCHDOWN_APPROACH_MM=10` — same pattern as `showcase_v0_i3_full_pipettebot_rows`) → post-cycle Z-only re-home → linger at Z=0 → park at (0, 0, 0). Defaults exercise both X and Y (SOURCE diagonal-from DEST). Gracefully runs gantry-only when `PIPETTE_PORT` is unset (`_LoggingPipette` stub satisfies the `_Pipette` protocol).
- **`tools/gantry_repl.py`** — interactive G-code REPL with per-firmware cheat-sheet dispatch. Auto-detects firmware via `pipettebot.devices.discover()`; `--device {marlin,smartto,unknown}` overrides the auto-detect. Reads `PRINTER_PORT`. Replaces `tools/marlin_repl.py` + `tools/smartto_repl.py`.
- **`tools/gantry_probe.py`** — read-only diagnostic + capability probe for any G-code firmware. Same auto-detect via `discover()`. Nine non-motion candidates (six original — `M503`/`M400`/`M203`/`M204`/`M205`/`M501` — plus `M220 S100` / `M211 S1` / `M85 S0` for feedrate scale, soft endstops, idle timeout). Per-family `QUIRKS` footer surfaces operator notes (e.g. Smartto's `M503` no-op, `G1 X Y` silent acceptance, `G28 Z` dive). Replaces `tools/smartto_probe.py`.
- **Test coverage** — `tests/tools/test_gantry_repl_cli.py` and `tests/tools/test_gantry_probe_cli.py` (12 in-process CLI tests). `tests/test_devices.py` extended with safe_home / polled-Z descent coverage (~10 new tests + Hypothesis property test on M115 parsing). Total suite: 121 passed, 6 skipped.
- **ADR 0005 — PC-as-host** (`docs/adr/0005-pc-as-host.md`). Formalizes the existing "no firmware modifications in v0" policy with the full Stage 0-2c escalation path and trigger conditions for each stage. Unblocks Stage 1+ firmware issues, which require an ADR to exist before merging per `AGENTS.md` rule 4.
- **Pi 3 B+ deploy infrastructure**: `tools/deploy/bootstrap.sh`, `tools/deploy/deploy.sh`, `tools/deploy/orchestrator.service`, `tools/deploy/99-pipettebot.rules` (udev), and a new `make check_deploy` target (shellcheck + bats + `systemd-analyze verify` + best-effort `udevadm`). Both scripts support `--dry-run`. Documents the CP2102N VID:PID collision between i3 Mega and dPette as a known limitation requiring per-unit `ATTRS{serial}` rules.
- **`_ArmController` Protocol** in `src/pipettebot/so101/orchestrator.py` — decouples type-checking from the optional `[orchestrator]` extra; the real `so101.arms` import now only happens at runtime inside `load_so101_controller()`.
- **Slicer tooling**: `make slice PART=<name>` (STL -> tracked `hardware/bgcode/<area>/<part>.bgcode` via named Input Shaper presets), `make setup_prusa_presets` (extracts MK4 IS presets from the system PrusaSlicer bundle into `~/.config/PrusaSlicer/`), `make dev_diagram` (wraps the diagramforge dev server).
- **`tools/cad/i3/carriage_dpette_mount_frictionfit.py`** — a self-contained, clearly-labeled (`parts.json` `"status": "testing"`) preservation of an abandoned carriage-mount design iteration (glue/friction-fit upper clamp, J-hook lower clamp) reached through real physical dry-fit testing on a since-diverged branch. Kept as reference/testing material, not a production candidate — see issue #75 for why it was abandoned.
- **`tools/cad/view.py`** — push a named part to the ocp-vscode browser viewer for design review. **`tools/slicer/upload_to_prusalink.py`** — PrusaLink HTTP upload with credentials read from `~/.cloud-credentials` (permission-checked, never committed). **`tools/slicer/print_carriage_assembly.py`** — batch-prints the friction-fit testing mount's 4 main pieces as one pre-arranged bed layout.
- **`COLUMN_PITCH_MM = 9.0`** constant in `src/pipettebot/bot.py` (re-exported from `pipettebot`) — the dPette+ 8-channel's SBS-matching row pitch, for callers computing column XY offsets by hand. Documents the physical constraint that all 8 channels share one piston bar (no independent per-channel volume).
- **Hypothesis property test** (`tests/test_gantry.py`) asserting `GcodeGantry.move_to()` emits well-formed `G1` lines (field order, 3-decimal precision, feedrate, single terminating newline) across the full float domain.
- **Pre-push validate guidance** in `CONTRIBUTING.md`: an optional three-line `.git/hooks/pre-push` snippet running `make validate`, plus a `--no-verify` emergency-skip note.
- `scriv` added to the `dev` extra — the `[tool.scriv]` config and `changelog.d/` fragment directory existed already but the CLI itself was never added as a dependency.
- **`tools/motion_profile_plot.py`** (closes #116) — renders three design-review SVGs to `hardware/svg/motion-profile/`: per-axis kinematics under the active `MotionProfile`'s M203/M201/M205 caps, a three-view path plot, and a deck-layout top view replacing the ASCII sketch in `docs/sketches/deck-layout-rows-script.md`. Deck geometry is read from `examples/showcase_v0_i3_full_pipettebot_rows.py` via reflection so the plot can't drift from what the gantry actually receives. New optional `viz` extra (`matplotlib`) and `viz` pytest marker; `make render_motion_profile MOTION_PROFILE=slow|mid|fast` (default `mid`).
- **`tools/cad/util/theme_svgs.py`** now content-sniffs matplotlib vs. build123d SVGs and applies the right dark-mode CSS for each dialect — matplotlib's inline `style=` attributes and unstyled vector-glyph text need different selectors than build123d's bare `stroke="rgb(...)"` output. Verified against a real `polyfetch --color-scheme dark` screenshot, not just code review.

### Fixed

- **`tests/tools/cad/test_parts_smoke.py`** referenced two CAD files (`labware/tip_rack_holder.py`, `labware/plate_holder.py`) removed months earlier when they were consolidated into `labware/deck_plate.py`'s combined assembly. Replaced with the part that's actually registered in `tools/cad/parts.json`.
- **`.gitignore`** was missing `hardware/step/` despite STEP export existing since the original deck-plate PR — generated STEP files were untracked-but-visible in every `git status` since.

### Removed

- `tools/marlin_repl.py` — superseded by `tools/gantry_repl.py`.
- `tools/smartto_repl.py` — superseded by `tools/gantry_repl.py`.
- `tools/smartto_probe.py` — superseded by `tools/gantry_probe.py`.
- `FirmwarePolicy.port_env_aliases` field — superseded by the single `PRINTER_PORT_ENV` constant.

## [0.1.0] — 2026-05-23

Second tagged release. Adds Geeetech A30 / Smartto firmware bring-up,
experiment + motion profile modules, the 3D-parts CAD/slicer pipeline,
six end-to-end showcase scripts, and a substantial doc + governance
buildout.

### Added

- **Geeetech A30 / Smartto bring-up** — `tools/smartto_probe.py` (read-only diagnostic + capability probe, 6 non-motion candidates classified SUPPORTED/UNSUPPORTED/PARTIAL/SILENT) and `tools/smartto_repl.py` (interactive REPL at 115200 baud). Live capability probe confirmed `M400`/`M203`/`M204`/`M205`/`M501` supported on Smartto v1.37.58 — Marlin-compatible motion surface. Operational caveat: `G28 Z` dives on this build (probe-pin variant); v0 routes around via `G28 X Y` + manual `G92 Z0`.
- **Experiment-profile loader** — `pipettebot.experiment_profile.load_experiment_profile` (TOML) + `PIPETTE_PROFILE` env on every dpette showcase. Sample profiles in `examples/experiment_profiles/`. Phase 1 of #79 (#82).
- **Motion-profile module** — `pipettebot.motion_profile` bundles SLOW/MID/FAST profiles; selectable via `MOTION_PROFILE`; emits `M203/M201/M204/M205` bootstrap. Design rationale in [ADR 0003](docs/adr/0003-motion-profile-bundled-constants.md).
- **Shared CLI env-var resolution** — `pipettebot.cli_profile` (`build_volumes()`, `resolve_profile()`) consumed by every showcase. 16 unit tests.
- **Showcase scripts** — `home_G28_fast`, `showcase_v0_pipette_sim`, `showcase_v0_tip_pickup_release`, `showcase_v0_full_plate`, `showcase_v0_full_pipettebot`, `showcase_v0_full_pipettebot_rows`, `showcase_v0_full_dpette_cycles`.
- **Hardware bring-up tools** — `tools/preflight.py` (auto-discovers ports, `--export` for shell `eval`, dPette retry on standby), `tools/marlin_repl.py` (G-code REPL with cheat-sheet), `tools/diagnose_axis.py` (per-axis safe motion), `tools/setup_pi.sh` (Pi provisioning, #65).
- **3D parts pipeline** — `tools/cad/` (build123d manifest-driven `render.py` + `parts.json`: dPette cradles, tip ejector, carriage mount, deck plate, measurements module, reusable `make_clamp_bore` primitive) and `tools/slicer/validate.py` (OrcaSlicer-first printability gate with PrusaSlicer fallback).
- **`pipettebot.gantry.open_marlin_port()`** — opens at 250000 baud with Linux `TCSETS2 + BOTHER` fallback for Python builds missing `termios.B250000` (#30).
- **Docs** — `UserStory.md` (personas + workflows), `deck-layout.md` (220 × 220 mm deck-frame spec), `marlin-commands.md` (G/M-code reference), `sbc-deployment.md` (Pi-on-printer path). Two research logs: `cad-alternatives.md` (AI-CAD evaluation: GenCAD/EvoCAD/evo-cad — all SKIP/TRACK, none adopted) and `gantry-firmware-alternatives.md` (Geeetech A30 + Smartto). Three ADRs (0001 repo structure, 0002 cadkit extraction, 0003 motion-profile constants).
- **CI** — `.github/workflows/codeql.yml` (Python security-and-quality) and `.github/dependabot.yml` (weekly Actions + pip).
- **Agent governance** — `.claude/rules/{compound-learning,context-management,core-principles,testing,cad-script-conventions,slicer-profile-source-of-truth,i3-carriage-payload-budget,cad-printability-gate}.md`. `AGENT_LEARNINGS.md` first entry. Adoption of `qte77-claude-code-plugins` marketplace (8 plugins).

### Changed

- **Repo identity** migrated `Lambda-Biolab` → `qte77` across README, SECURITY, CONTRIBUTING, pyproject, NOTICE, ADRs, docs. `dpette-usb-driver` and `so101-biolab-automation` URLs preserved.
- **Naming symmetry** for profile modules: `pipettebot.profiles` → `pipettebot.experiment_profile` (parallel with new `motion_profile`); `examples/profiles/` → `examples/experiment_profiles/`; `load_profile()` → `load_experiment_profile()`.
- **Showcase scripts deduplicated** through `pipettebot.cli_profile.build_volumes()` — shared `PIPETTE_PROFILE` / `PIPETTE_VOLUME_UL` precedence, identical banner shape.
- **Per-dive Z slowdowns + touchdown split** in `showcase_v0_full_pipettebot_rows.py` — `TOUCHDOWN_APPROACH_MM=10.0` fast-then-slow approach reduces per-dive wall-clock by ~80% while preserving bed-contact protection.
- **Showcase geometry tightened** — `TRAVEL_Z` 125 → 95 mm (~6 s/cycle saved); `SBS_COL_PITCH` −10 → −9 mm (correct SBS standard, cumulative pitch error eliminated); asymmetric tip-pickup Z constants (#82, #83).
- **`RELEASE_BAR_Y`** re-measured to 220 (was 190 — hook is on the chassis frame, not the bed).
- **README** reworked with badge row, comparison table (Science Jubilee, OT-2 at $15,950), Quickstart hardening; YAML frontmatter dropped; demo GIF centred.
- **Makefile** reorganized: `help` is default; recipes grouped by `# MARK:` section; per-tool `.venv/bin/<tool>`-first dispatch with `uv run` fallback; recipe renames (`init` → `setup_dev`; new `setup_uv` / `setup_prod` / `setup_all`); `setup_diagramforge` SHA-pinned; `setup_*` recipes pass `--inexact` to `uv sync`.
- **Python pin** tightened to `>=3.11,<3.13` (cadquery-ocp → VTK lacks cp313 wheels). Ruff `mccabe.max-complexity` lowered to 8. `tools/cad/**` + `tools/slicer/**` excluded from mypy strict.
- **Slicer profiles** renamed `pla_plus_02mm.ini` / `tpu_95a_02mm.ini` — fabrication moves to Prusa-class machines (stripped i3 prints nothing).
- **`tools/preflight.py`** auto-discovers ports with stub-mode detection + standby retry; passes when *either* i3 Mega or dPette is found (was: required both) (#23, #37).
- **Marlin USB baud** corrected to 250000 (was 115200 — Anycubic stock + MARLIN-AI3M).
- **`AGENT_REQUESTS.md`** repurposed from per-area backlog into agent-to-human / agent-to-agent communication channel; open items migrated to GitHub issues.
- **`examples/preflight.py`** → `tools/preflight.py` (hardware diagnostic, not usage example).
- **`examples/showcase_v0_pipette_sim.py`** replaces `showcase_v0.py` as the canonical hardware demo (raw-serial read-until-`ok`, plunger simulated via gantry Z, G-code tee to disk).
- **`docs/hardware.md`** documents CH340 + CP2102N USB-bridge variants and `M115` tiebreaker.
- **`.claude/rules/motion-safety.md`** + `pipette-delegation.md` gain YAML `paths:` frontmatter so they only load in `src/`/`examples/`/`tests/` contexts.
- **`docs/sbc-deployment.md`** Pi setup invokes `tools/setup_pi.sh` via `curl | bash` (was 5-step manual recipe) (#65).
- README, CONTRIBUTING.md, docs/calibration.md copy-paste blocks no longer break stock zsh (`interactive_comments` off) (#25).

### Fixed

- CAD primitive stacking (build123d `Cylinder`/`Cone` are centred-at-origin), SVG export hidden-line projection, post connectivity in carriage mount.
- Slicer overhang keyword false-positives — tightened from generic terms to literal slicer warning phrases.
- USB port discovery for CP2102N on newer Anycubic batches (#23, #25, closes #18).
- Marlin USB at 250000 baud on Python builds missing `termios.B250000` (Linux `TCSETS2 + BOTHER` ioctl) (#30).
- Default Marlin baud was 115200; now 250000 to match Anycubic stock + MARLIN-AI3M (closes #17).
- Quickstart copy-paste no longer breaks on stock zsh (closes #15).

### Removed

- `examples/showcase_v0.py` — superseded by `examples/showcase_v0_pipette_sim.py` (#23).
- `.github/social-preview.png` — repo now uses GitHub's default open-graph card.

## [0.0.1] — 2026-05-07

First tagged release. Working v0 prototype with software-only validation
and a hardware onboarding path.

### Added

- v0 pipettebot package: `GcodeGantry`, `PipetteBot`
- `examples/showcase_v0.py` — happy-path aspirate/dispense demo
- `examples/preflight.py` — non-actuating port + firmware sanity check
- `docs/hardware.md` — i3 Mega + dPette wiring, port discovery
- `docs/calibration.md` — well-A1 origin procedure, 9 mm pitch check
- `.github/social-preview.png` — repo social preview matching Lambda Biolab style
- Mocked-serial test suite (9 tests, both Python 3.11 and 3.12)
- CI workflow (uv-based; ruff format/lint, mypy strict, pytest mocked)
- Apache-2.0 license + NOTICE crediting Anycubic i3 Mega, Marlin, dpette-usb-driver
- AGENTS.md / CLAUDE.md / GEMINI.md doc hierarchy mirroring Agents-eval
- AGENT_REQUESTS.md backlog with deferred liquid-handling, deck, firmware, hardware items
- `.claude/rules/motion-safety.md` and `.claude/rules/pipette-delegation.md`
- Makefile recipes via `uv run`; pre-commit removed in favor of Makefile + CI

### Pinned

- `dpette` dependency pinned to commit SHA for reproducibility

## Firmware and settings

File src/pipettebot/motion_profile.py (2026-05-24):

"""Motion-profile factors for the i3 Mega gantry bootstrap.

Three named profiles (`slow` / `mid` / `fast`) selectable at runtime
via the `MOTION_PROFILE` env var. Each profile renders to four M-codes
(M203 / M201 / M204 / M205) sent at the bootstrap of every gantry-using
example script.

Usage in examples::

    from pipettebot.motion_profile import select_profile

    profile = select_profile(os.environ.get("MOTION_PROFILE"))
    if profile is None:
        # opt-out: Marlin keeps RAM/EEPROM motion settings as-is
        ...
    else:
        for cmd in profile.as_marlin():
            gsend(link, cmd, gcode_out=gcode_out)

`MID` is the default (returned when env is unset). Empty string or
`"off"` returns ``None`` (opt-out — Marlin keeps RAM/EEPROM motion
settings as-is). Unknown names raise ``ValueError`` with the valid
set listed in the message.

Profile semantics
-----------------

Profiles scale by exact factor of 3x: SLOW x3 = MID, MID x3 = FAST.
MID is the anchor (operator-validated baseline); SLOW divides accel +
jerk by 3 for cautious runs, FAST triples them for time-critical
tours. Accel is rounded to integer mm/s^2 (M201/M204 want integers);
jerk keeps two decimals.

- **MID** (default): liquid-handling friendly. Z accel held at the
  leadscrew-friendly floor of 200 mm/s² (balances dive speed with
  leadscrew + cantilever shock). X/Y accel kept careful (600 / 800
  mm/s²) to limit plate slosh on Y and tip-pendulum + droplet shed
  on X. Tight classic jerk. This is what every showcase script gets
  when MOTION_PROFILE is unset.

- **SLOW** (MID / 3): extra-gentle. Z accel 67, X/Y accel 200/267,
  jerk 1.0/1.67/0.07. Use for first-time runs on a new fixture, very
  viscous reagents, or any time you want the gantry to look obviously
  cautious.

- **FAST** (MID x3): quicker tours. Z accel 600, X/Y accel 1800/2400,
  jerk 9/15/0.6. Use once you know the deck geometry is solid and
  liquid surface quality is acceptable — saves cycle time at the cost
  of more aggressive motion (more meniscus disturbance, more
  tip-pendulum swing, harsher leadscrew starts).

Quick comparison
----------------

============  ====  ====  =====  ====
Field         SLOW   MID   FAST  step
============  ====  ====  =====  ====
accel_x        200   600   1800  x3
accel_y        267   800   2400  x3
accel_z         67   200    600  x3
accel_default  200   600   1800  x3
jerk_x         1.0   3.0    9.0  x3
jerk_y        1.67   5.0   15.0  x3
jerk_z        0.07   0.2    0.6  x3
============  ====  ====  =====  ====

Feedrate caps (M203 X500 Y500 Z20) are shared across all profiles —
they reflect the leadscrew mechanical limit on Z and a reasonable XY
cruise speed, not a tuning choice. The dialed lever is per-axis accel
(M201) and classic jerk (M205).
"""

from __future__ import annotations

from dataclasses import dataclass


@dataclass(frozen=True)
class MotionProfile:
    """Marlin motion profile — feedrate caps, per-axis accel, classic jerk.

    Feedrate caps (M203) are shared across SLOW/MID/FAST by default; the
    dialed lever is `accel_*` (M201) and `jerk_*` (M205). The dataclass
    is frozen so profile constants are immutable at runtime.
    """

    name: str
    accel_x: int
    accel_y: int
    accel_z: int
    accel_default: int
    jerk_x: float
    jerk_y: float
    jerk_z: float
    feed_x: int = 500
    feed_y: int = 500
    feed_z: int = 20
    jerk_e: float = 0.0

    def as_marlin(self) -> tuple[str, str, str, str]:
        """Render as the four bootstrap M-code strings: M203, M201, M204, M205."""
        return (
            f"M203 X{self.feed_x} Y{self.feed_y} Z{self.feed_z}",
            f"M201 X{self.accel_x} Y{self.accel_y} Z{self.accel_z}",
            f"M204 P{self.accel_default} R{self.accel_default} T{self.accel_default}",
            f"M205 X{self.jerk_x:g} Y{self.jerk_y:g} Z{self.jerk_z:g} E{self.jerk_e:g}",
        )


# SLOW / MID / FAST scale by exact 3x. MID is the operator-validated
# baseline; SLOW = MID/3, FAST = MID*3. Third/triple makes the
# difference obvious on the bench and keeps the relative spacing
# predictable for anyone tuning per-leg feedrates inside these caps.
# Non-clean MID values (800, 200, 5, 0.2) produce non-integer SLOW
# accels — rounded since M201/M204 want integer mm/s^2.
SLOW = MotionProfile(
    name="slow",
    accel_x=200,
    accel_y=267,
    accel_z=67,
    accel_default=200,
    jerk_x=1.0,
    jerk_y=1.67,
    jerk_z=0.07,
)
MID = MotionProfile(
    name="mid",
    accel_x=600,
    accel_y=800,
    accel_z=200,
    accel_default=600,
    jerk_x=3,
    jerk_y=5,
    jerk_z=0.2,
)
FAST = MotionProfile(
    name="fast",
    accel_x=1800,
    accel_y=2400,
    accel_z=600,
    accel_default=1800,
    jerk_x=9,
    jerk_y=15,
    jerk_z=0.6,
)

PROFILES: dict[str, MotionProfile] = {"slow": SLOW, "mid": MID, "fast": FAST}
DEFAULT_PROFILE = MID

_OPT_OUT = {"", "off"}


def select_profile(env_value: str | None = None) -> MotionProfile | None:
    """Pick a bundled motion profile by name (case-insensitive, whitespace-trimmed).

    Returns:
        - `DEFAULT_PROFILE` (`MID`) when `env_value` is `None` (env unset).
        - `None` for opt-out (`""` or `"off"` after trim+lowercase).
        - The named profile from `PROFILES` otherwise.

    Raises:
        ValueError: if the name is non-empty and not in `PROFILES`.
    """
    if env_value is None:
        return DEFAULT_PROFILE
    name = env_value.strip().lower()
    if name in _OPT_OUT:
        return None
    if name not in PROFILES:
        valid = sorted(PROFILES)
        raise ValueError(
            f"Unknown motion profile {name!r}; valid: {valid} or '' / 'off' to skip"
        )
    return PROFILES[name]

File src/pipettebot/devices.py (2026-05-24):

"""Device-discovery substrate: M115-based firmware identification.

Pure data + parser layer. No I/O beyond `discover()`, which opens a serial
port to elicit an `M115` reply. Every other function is pure-Python and
testable without hardware.
"""

from __future__ import annotations

import os
import re
import time
from dataclasses import dataclass
from typing import TYPE_CHECKING

from pipettebot.gantry import GcodeGantry, open_gcode_port, send_and_wait_for_ok

if TYPE_CHECKING:
    from collections.abc import Callable, Mapping

# Single env var operators set to point at the gantry's USB-serial path.
# Resolved by `resolve_port()`. Used uniformly by every example, tool, and
# discover-driven helper; printer model is identified by `discover()`, not
# by which env var was set.
PRINTER_PORT_ENV = "PRINTER_PORT"

# (substring to match in M115 reply, firmware family it identifies).
# Order matters: the first matching fingerprint wins. Keep more-specific
# matches before less-specific ones.
FIRMWARE_FINGERPRINTS: tuple[tuple[str, str], ...] = (
    ("MARLIN", "marlin"),
    ("Marlin", "marlin"),
    ("MACHINE_TYPE:A30", "smartto"),
    ("PROTOCOL_VERSION:V1.0", "smartto"),
)


@dataclass(frozen=True)
class DiscoveredDevice:
    """Pure observation: what the device replied to M115 at what baud.

    No behavior, no policy decisions. `firmware_family` is the result of
    `classify(raw_m115)`; `firmware_version` and `machine_type` are
    extracted whitespace-bounded values of `FIRMWARE_NAME:` and
    `MACHINE_TYPE:` fields (None if absent).
    """

    baud: int
    raw_m115: str
    firmware_family: str
    firmware_version: str | None
    machine_type: str | None


@dataclass(frozen=True)
class FirmwarePolicy:
    """Per-family behavior decisions: how to home, default baud.

    Stable while machine models proliferate. A new printer model running an
    already-known firmware adds zero code; a new firmware family adds one
    entry to `FIRMWARE_POLICIES` plus matching `FIRMWARE_FINGERPRINTS`.

    Port resolution is firmware-agnostic: every operator sets a single
    `PRINTER_PORT` env var (see `resolve_port()`). Per-family port aliases
    were collapsed when the env-var convention was unified.
    """

    family: str
    home_strategy: str
    preferred_baud: int


# Per-firmware policies. The `unknown` entry is the conservative fallback
# returned by `policy_for()` when classification fails — `manual_only`
# homing forbids the gantry layer from calling `G28` blind.
FIRMWARE_POLICIES: tuple[FirmwarePolicy, ...] = (
    FirmwarePolicy(family="marlin", home_strategy="full_g28", preferred_baud=250000),
    FirmwarePolicy(
        family="smartto", home_strategy="xy_then_polled_z", preferred_baud=115200
    ),
    FirmwarePolicy(
        family="unknown", home_strategy="manual_only", preferred_baud=115200
    ),
)


def classify(raw_m115: str) -> str:
    """Return the firmware family inferred from a raw M115 reply.

    Substring-matches each fingerprint in `FIRMWARE_FINGERPRINTS` in order;
    the first hit wins. Returns `"unknown"` if no fingerprint matches —
    callers should fall through to the conservative `unknown` policy.

    Args:
        raw_m115: Concatenated, newline-separated reply lines (no `ok`
            terminator).

    Returns:
        Firmware family identifier (lowercase short name).
    """
    for fingerprint, family in FIRMWARE_FINGERPRINTS:
        if fingerprint in raw_m115:
            return family
    return "unknown"


def _extract(raw: str, key: str) -> str | None:
    """Pull `key:VALUE` from `raw` (VALUE = next whitespace-bounded token)."""
    match = re.search(rf"\b{re.escape(key)}:(\S+)", raw)
    return match.group(1) if match else None


def parse_m115(raw: str, baud: int) -> DiscoveredDevice:
    """Parse an M115 reply body into a DiscoveredDevice observation.

    Pure function — no I/O. Extracts whitespace-bounded values of
    `FIRMWARE_NAME:` and `MACHINE_TYPE:` if present, classifies firmware
    family via `classify()`, and packages everything with the supplied
    `baud`.

    Args:
        raw: Joined-line text body of an M115 reply (no `ok` terminator).
        baud: Baud rate at which the reply was received.

    Returns:
        Observation snapshot suitable for `policy_for()` lookup.
    """
    return DiscoveredDevice(
        baud=baud,
        raw_m115=raw,
        firmware_family=classify(raw),
        firmware_version=_extract(raw, "FIRMWARE_NAME"),
        machine_type=_extract(raw, "MACHINE_TYPE"),
    )


def policy_for(device: DiscoveredDevice) -> FirmwarePolicy:
    """Return the FirmwarePolicy matching `device.firmware_family`.

    Falls back to the `unknown` policy (conservative `manual_only` homing)
    when no registered policy matches the observed firmware family.

    Args:
        device: Observation from `parse_m115()`.

    Returns:
        The matching policy, or the `unknown` fallback.
    """
    for policy in FIRMWARE_POLICIES:
        if policy.family == device.firmware_family:
            return policy
    return next(p for p in FIRMWARE_POLICIES if p.family == "unknown")


def resolve_port(env: Mapping[str, str] | None = None) -> str | None:
    """Return the operator's `PRINTER_PORT` env value, or None if unset.

    Args:
        env: Mapping to read from. Defaults to `os.environ` so operators can
            use the usual shell-export workflow.

    Returns:
        The port string if `PRINTER_PORT` is set and non-empty, else None.
    """
    source = env if env is not None else os.environ
    value = source.get(PRINTER_PORT_ENV)
    return value if value else None
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

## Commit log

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2026-05-07 fix: green CI for v0 scaffold (#2)
    * fix: ruff lint failures (TCH, E501, isort)
    CI was rejecting the merged main on ruff checks. Three categories:
    - TC001 in src/pipettebot/bot.py — GcodeGantry was a runtime import but
    used only as a type annotation. Move it under
    if TYPE_CHECKING to make the runtime cost zero.
    - E501 in src/pipettebot/gantry.py — _SerialPort docstring was 90 chars;
    shortened to fit the 88-char limit.
    - I001/TC002/TC003 across tests/ — declare 'tests' as first-party so
    isort groups it next to pipettebot, and add per-file-ignores for the
    type-checking-block rules in tests/ where injected fixtures appear as
    parameter annotations only.
    uv run ruff check / f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
    [bot.py, gantry.py]
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2026-05-07 chore: remove .github/social-preview.png; use GitHub default (#14)
    The custom social preview added in v0.0.1 turned out unnecessary —
    GitHub's default repo card is good enough for now. Drop the asset
    and update references:
    - .github/social-preview.png deleted
    - .github/assets/README.md: drop the social-preview slot row; note
    that GitHub's default open-graph card is intentional
    - AGENT_REQUESTS.md: drop the [x] Social-preview entry
    - CHANGELOG.md: add an [Unreleased] section noting the removal
    The v0.0.1 tag still points at the squash commit that included the
    PNG, so the historical 0.0.1 entry stays accurate. Issue #5
    (hardware photo set + showcase GIF) will be edited separately to
    drop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
2026-05-08 chore(.claude): mirror compound-learning + context + core-principles rules into the repo (#20)
    The repo already ships motion-safety.md and pipette-delegation.md
    under .claude/rules/. This commit pins three more general-purpose
    agent rules (byte-identical to the maintainer's user-global versions)
    into the repo so any contributor running Claude Code in this tree
    gets the same governance even without the equivalent dotfiles in
    $HOME.
    - compound-learning.md Promotion path for repeated mistakes:
    1st occurrence -> fix inline,
    2nd -> AGENT_LEARNINGS.md,
    3rd -> .claude/rules/,
    recurri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
2026-05-08 docs: add Path 2 (SBC-on-printer) deployment guide (#21)
    Adds docs/sbc-deployment.md describing how to replace the laptop tether
    with a small Linux board (Raspberry Pi Zero 2 W or Pi 4) zip-tied to
    the printer chassis.
    Both the i3 Mega and the dPette are USB devices (CH340/CP2102N and
    CP2102 respectively) — neither is a USB host. Plugging them directly
    together does not work; see issue #18 and the existing hardware.md
    discussion. The two paths that make the printer + pipette
    self-contained are:
    Path 2 (this doc): mount a Pi as USB host for both. No firmware
    patch, no soldering, no warranty voided.
    Cost: ~$25-40. Replaces laptop tether but does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
2026-05-08 feat: consolidate examples on showcase_v0_pipette_sim with auto-discovery preflight (#23)
    Drops examples/showcase_v0.py and replaces it with showcase_v0_pipette_sim.py
    as the canonical hardware demo. Updates the preflight, README, AGENTS,
    and docs/{hardware,calibration} + AGENT_REQUESTS to point at the new
    example. Subsumes branches fix/preflight-auto-discovery and
    feat/showcase-pipette-sim — both become redundant after this lands.
    Why drop the original showcase_v0.py:
    - Hardcoded /dev/ttyUSB0 + 115200 baud — wrong on macOS and wrong
    for every Anycubic stock / MARLIN-AI3M printer (issue #17). The
    file never actually ran end-to-end on the reference hardware.
    - Relied on Gcod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
    [preflight.py, showcase_v0_pipette_sim.py]
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2026-05-08 docs: close #15, #18 + governance follow-ups (#25)
    * docs(hardware): document CH340 + CP2102N variants and M115 tiebreaker
    Closes #18.
    The i3 Mega ships with two USB-UART bridges in the wild:
    - Older boards: CH340 (`1a86:7523`)
    - Newer batches and many MARLIN-AI3M-flashed units: CP2102N (`10c4:ea60`)
    When the printer is on a CP2102N, it shares VID:PID with the dPette
    (also CP2102, `10c4:ea60`), so descriptor-only disambiguation breaks.
    Document this and add an `M115`-probe tiebreaker the user can run
    manually (preflight.py already does it programmatically since #23).
    Also corrects the stock baud from 115200 to 250000 — Anycubic stock
    and MARLIN-AI3M both ship at 250000; this matches t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
2026-05-08 docs: post-#23 stale refs + populate [Unreleased] CHANGELOG (#27)
    * fix(examples): drop stale companion refs in showcase docstring; point at #26
    The docstring referenced two files that no longer exist:
    - showcase_v0_dry_run.py — never existed in the repo
    - showcase_v0.py — deleted in #23
    Replace the companion paragraph with a one-liner stating this is the
    canonical v0 demo. Also retarget the GcodeGantry._send-bug citation
    from "issue #19" (which is actually a closed PR about .gitignore) to
    the newly-opened #26 that tracks the bug for real.
    * docs(CHANGELOG): populate [Unreleased] with post-v0.0.1 work
    Six PRs landed since v0.0.1 without changelog entries (#16, #19, #20,
    #21, #23, #2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
    [showcase_v0_pipette_sim.py]
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2026-05-09 fix(preflight): use TCSETS2 ioctl for 250000 baud on Linux (#30)
    * fix(preflight): use TCSETS2 ioctl for 250000 baud on Linux
    Some Python builds (Fedora + 3.13) don't expose `termios.B250000`,
    and pyserial 3.5's `BAUDRATE_CONSTANTS` doesn't list it either, so
    the Marlin probe crashed with `termios.error: (22, 'Invalid argument')`
    on the first `serial.Serial(port, 250000)` call.
    Add `_open_marlin_port()` that falls back to opening the port at 9600
    and switching to 250000 via the Linux-only `TCSETS2 + BOTHER` ioctl.
    The kernel accepts arbitrary baud rates this way regardless of which
    constants Python's `termios` module exposes. macOS keeps the existing
    pyserial path.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
    [gantry.py, preflight.py, showcase_v0_pipette_sim.py]
2026-05-09 feat(tools): diagnose_axis (X/Y/Z) + marlin_repl with command cheat-sheet (#35)
    * feat(tools): add diagnose_z.py — safe Z-axis motion diagnostic
    Establishes `tools/` per the AGENTS.md "hardware experiments" convention.
    First entry is `diagnose_z.py`, which lets you check Z-axis motion on a
    headless gantry without running `G28 Z` (impossible after the inductive
    probe was removed with the print head).
    Sequence: M119 (endstop status) → confirmation prompt → G91 (relative
    mode) → up-direction Z steps under per-step confirmation → down-direction
    Z steps under per-step confirmation → G90 (absolute mode) on exit. The
    G90 cleanup runs even on Ctrl-C or Marlin error. Defaults are
    conser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
    [diagnose_axis.py]
2026-05-09 docs(marlin-commands): add reference table for common G/M-codes (#33)
    New `docs/marlin-commands.md` mirrors the cheat-sheet baked into
    `tools/marlin_repl.py` — same content, fuller prose, browseable.
    Sections: identification/state, halt/recovery, motion, homing,
    steppers, sensor overrides, EEPROM. Includes:
    - Coordinate orientation table (front view): X-min = LEFT, Y-min =
    FRONT, Z-min = BED. Connects `G0 X-1` to physical direction so
    M119 readings and homing failures are easier to interpret.
    - Project-specific gotchas: M412 not on 1.1.9, G28 Z risk on a
    headless gantry, z2_min as a stock-AI3M artifact, 250000-baud
    Linux ioctl fallback.
    Cross-links to AGENT_LEARNINGS.md and AGENT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
2026-05-09 chore(preflight): move to tools/ + feat: --export flag for shell-eval chaining (#36)
    * chore(preflight): move examples/preflight.py → tools/preflight.py
    Preflight is a non-actuating hardware diagnostic — port discovery and
    firmware sanity check, no pipetting workflow. AGENTS.md classifies that
    as `tools/` ("hardware experiments"), not `examples/`. Moving it makes
    the categorization match the convention now that `tools/` exists.
    - `git mv examples/preflight.py tools/preflight.py`
    - README, docs/calibration.md, docs/hardware.md, docs/sbc-deployment.md,
    docs/marlin-commands.md updated to the new path
    - examples/showcase_v0_pipette_sim.py and tools/{diagnose_axis,marlin_repl}.py
    error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
    [diagnose_axis.py, preflight.py, showcase_v0_pipette_sim.py]
2026-05-09 feat(preflight): pass when either i3 Mega or dPette is found (#37)
    In v0 the gantry and the pipette are exercised independently — the
    showcase example uses the i3 alone with a simulated piston, and pipette
    tests use the dPette alone. Requiring both devices to be present for
    preflight to succeed didn't match that usage.
    `main()` now succeeds (exit 0) as long as at least one device probes
    cleanly, and reports `(not found)` for whichever is missing. Only
    "nothing answered at all" returns exit 1. Existing `I3MEGA_PORT` /
    `PIPETTE_PORT` env overrides keep their meaning.
    [preflight.py]
2026-05-09 docs(readme,changelog): surface new tools/ + chain pattern; backfill PR refs (#38)
    README: add a "Hardware diagnostics (tools/)" section listing
    preflight, diagnose_axis, marlin_repl with one-line purpose; show
    the `eval $(... --export)` chain pattern in the quickstart;
    correct the misleading "real pipette I/O via tools/preflight.py"
    statement (preflight only probes); link docs/marlin-commands.md
    and docs/sbc-deployment.md from the Documentation index.
    CHANGELOG: backfill PR references (#30, #33, #35, #36, #37) on the
    [Unreleased] entries that were merged without them.
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2026-05-10 docs: research findings (combined) — design rationale, Pi 1 B+ caveats, audit fixes (#46)
    Combined-and-cleaned version of the docs/research-findings branch.
    Originally 6 topical commits (hardware, 3d-parts, sbc+calibration,
    audit cleanup, second-pass audit, md lint) plus a cherry-pick of the
    format-fix from PR #39. Squashed here because the original branch
    hit a persistent README.md filesystem lock during rebase, blocking
    git's normal history-replay. The applied patch is the cumulative
    diff vs main; content is identical to what those 6 commits would
    have produced.
    Content summary:
    - docs/3d-parts.md (NEW) — payload-budget math (canonical < 300 g
    total), Z envelope after print-head st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
2026-05-10 feat(tools/cad/i3): real carriage dPette+ mount geometry (split upper clamp) (#47)
    * feat(tools/cad/i3): real geometry for carriage dPette+ mount (split upper clamp)
    Replaces the placeholder stub with parametric build123d geometry.
    Two-piece design — required because the dPette+ is one rigid unit
    (lower body / upper barrel / top section permanently joined), so
    lateral horseshoe insertion of the Ø27 upper barrel is blocked by
    the wider sections above and below.
    - main: top plate (4× M4 in 21×13 mm pattern, bolts to underside of
    AI3M horizontal head-mount plate) + back-half of upper clamp
    (D-cavity opens to −Y, with 2× M3 holes for cap bolts) + vertical
    post + lower hor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
2026-05-10 chore(makefile): prefer .venv binaries to dodge uv-cache writes (#50)
    `uv run` updates `~/.cache/uv/` on every invocation, which fails on
    hosts where the cache is read-only (sandbox builds, sealed Pi images,
    some CI runners). Switch every uv-using target to the pre-built venv
    when `.venv/bin/python` exists, with a clean fallback to `uv run` for
    fresh clones where `make init` / `make setup_cad` haven't run yet.
    One target (`check_complexity`) keeps `uv run complexipy` — it's not
    part of `make validate`, runs rarely, and a venv-binary check for one
    more tool isn't worth the noise.
2026-05-10 fix(tools/cad/dpette): stack tip_ejection_bar primitives correctly (#52)
    build123d's `Cylinder` and `Cone` default to fully-centred-at-origin,
    not z-bottom-at-origin. The original `Pos(0, 0, BASE_THICKNESS / 2)`
    placed the post's CENTRE 2 mm above the origin, so the post spanned
    z ∈ [-28, 32] — its bottom half buried below the base, only its top
    half sticking up. The cone, positioned at z = BASE/2 + POST_HEIGHT,
    sat at z ∈ [59, 65] — completely detached from the post, with a 27 mm
    air gap between them.
    Slicer caught it: `floating object part, floating bridge anchors,
    loose extrusions, long bridging extrusions, empty layer WARN`.
    Fix: compute each primitive's centre position from th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
2026-05-12 feat(showcase): SBS column pitch −10 → −9 mm (standard SBS) (#83)
    * feat(showcase): SBS column pitch −10 → −9 mm (standard SBS)
    Standard SBS column pitch is 9 mm, not 10. The prior 10 mm value
    progressively drifted off-center; by cycle 11 the offset was a full
    column-to-column gap.
    - `SBS_COL_PITCH = -9.0` in both gantry-touching showcases.
    - New 11-cycle Y ladder (from `SBS_COL1_Y=190`):
    190, 181, 172, 163, 154, 145, 136, 127, 118, 109, 100
    (last column lands at Y=100 instead of Y=90 — 10 mm farther from
    the bed front).
    - Updated inline comments and the per-cycle Y formula docstrings.
    * docs(deck-layout): sync to −9 mm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
    [showcase_v0_full_pipettebot.py, showcase_v0_full_plate.py]
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2026-05-16 feat(showcase): v0 tip pickup + mechanical bar-release example (#91)
    * feat(showcase): add v0 tip pickup + mechanical bar-release example
    Drives a full mechanical tip cycle on the i3 Mega: pickup at the
    tip-box slot (X170 Y152, Z59 → Z119 clearance), traverse over the
    release bar at Z170, drop the handle hook into engagement from above
    (Z145), then lift to Z170 to actuate ejection — bar holds the handle
    while the body rises, handle descends relative to body and pops the
    tip off.
    No dPette serial traffic; ejection is purely mechanical via the fixed
    bar fixture above the deck. Constants carry deck-slot comments per
    .claude/rules/motion-safety.md. Adds the .gcode tee output to
    .gitignore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
    [showcase_v0_tip_pickup_release.py]
2026-05-17 feat(showcase): v0 row-tour plate fill with per-cycle tip recycle (#96)
    * feat(showcase): add v0 row-tour plate fill with per-cycle tip recycle
    New examples/showcase_v0_full_pipettebot_rows.py — sibling of
    showcase_v0_full_pipettebot.py with two structural changes:
    1. Per-cycle tip recycle. Each cycle does its own pickup from a fresh
    tip-box row and ejects at the release bar before the next pickup.
    The one-time pickup_tips() helper from full_pipettebot is replaced
    by a _cycle() that runs pickup → aspirate → dispense → eject.
    2. Row-major fill, configurable count. Cycles traverse 96-well rows
    (Y axis, +9 mm SBS pitch from Y=75) rather than columns. Count is
    driven by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
    [profiles.py, showcase_v0_full_pipettebot_rows.py]
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2026-05-17 feat(motion-profile): MOTION_PROFILE env selector + bundled factors (ADR 0003) (#113)
    * feat(examples): unified XYZ liquid-handling motion profile in bootstraps
    Every gantry-using showcase now installs the same motion profile in
    its bootstrap so chaining scripts leaves a known motion state:
    M203 X500 Y500 Z20 (peak feedrate caps; Z at leadscrew limit)
    M201 X1200 Y1500 Z80 (per-axis accel; Z softened from AI3M ~200
    for leadscrew + cantilever protection)
    M204 P1200 R1200 T1200 (default print / retract / travel accel)
    M205 X3 Y5 Z0.2 E0 (classic jerk — tight X for tip pendulum +
    droplet shed; tight Z for clean meniscus)
    home_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
    [experiment_profile.py, home_G28_fast.py, motion_profile.py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]
2026-05-17 cli_profile + rows PIPETTE_PROFILE + touchdown split + Y=220 + safety cap N=8 (#121)
    * feat(pipettebot): add cli_profile module for shared showcase env-var resolution
    Centralises PIPETTE_PROFILE / PIPETTE_VOLUME_UL handling so every
    showcase script returns (volumes_ul, banner) consistently. 16 tests
    cover both resolution paths (profile / constant) and unit_label
    parameterisation.
    Re-exported from pipettebot.__init__ as build_volumes + resolve_profile.
    * refactor(examples): use pipettebot.cli_profile in column + dpette-cycles showcases
    Drops the per-script _resolve_profile / _build_volumes / DEFAULT_VOLUME_UL
    duplicates and routes both showc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
    [cli_profile.py, showcase_v0_full_pipettebot.py, showcase_v0_full_pipettebot_rows.py]
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2026-05-18 Rows showcase: profile cap + README PIPETTE_PORT and so101 reference (#125)
    * docs(readme): add PIPETTE_PORT to rows showcase example
    The rows showcase needs both I3MEGA_PORT and PIPETTE_PORT for full
    hardware mode; the prior snippet omitted the pipette port. Lead with
    PIPETTE_PORT=/dev/ttyUSB1 so the example is concretely runnable.
    * fix(rows): cap PIPETTE_PROFILE length by NUM_CYCLES env
    build_volumes returns the profile's full volumes tuple unchanged, and
    _run uses len(volumes_ul) as the cycle count — so a profile silently
    overrides NUM_CYCLES and the MAX_NUM_CYCLES safety cap. A 12-volume
    profile would drive the tip-box past Y=246 mm i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
    [showcase_v0_full_pipettebot_rows.py]
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2026-05-20 SO-101 orchestrator: bin pickup after i3 final G28+M400 (#134)
    * feat(so101): orchestrator subpackage + capture CLI + arms config
    Adds the `pipettebot.so101` subpackage (composition only over
    `so101.DualArmController` — no subclassing, no override):
    - orchestrator.load_so101_controller / validate_sequence_positions / run_sequence
    - capture_position CLI (`pipettebot-capture-position`) for the teaching
    workflow: prints the follower's current joint vector as a yaml-paste
    line for configs/so101_arms.yaml.
    configs/so101_arms.yaml ships placeholder `demo_pickup_*` positions for the
    pickup-rotate bootstrap (issue #120). Real values come from leader teleop +
    the new capture CLI; see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
    [showcase_v0_full_pipettebot_rows.py]
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2026-05-23 chore(ruff): expand select per py-harden-ruff section 1 (#149)
    * chore(ruff): expand select per py-harden-ruff section 1
    Adopt the strictness ratchet from py-harden-ruff.md section 1:
    - Add ANN, D, PGH, PT, RUF, TC (renamed from TCH), TRY to select.
    - Add ignore = ["TRY003"] — long error messages outside exception classes
    are noisy on one-off defensive raises.
    - Add [tool.ruff.lint.pydocstyle] convention = "google".
    - Migrate per-file-ignores:
    - examples/* gains D + ANN + RUF unicode-ambiguity ignores (operator
    scripts; intentional × / – in technical comments).
    - tests/* widened to tests/** (covers nested test paths); appends D,
    ANN, PT, and RUF unicode-ambiguity ignores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
    [bot.py, experiment_profile.py, gantry.py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]
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2026-05-23 refactor(tools/preflight): use pipettebot.devices.discover() substrate (#152)
    * test(tools): add CLI contract tests for preflight (Red)
    Four in-process tests covering the device-discovery wiring that
    preflight will gain in the next commit:
    - exits 1 when no USB ports are present (passes today — exit-1 path
    exists in the current marlin-only flow).
    - export emits `I3MEGA_PORT=` for a marlin-classified device.
    - export emits `SMARTTO_PORT=` for an A30 / smartto-classified device.
    - export emits `GANTRY_PORT=` for an unrecognised firmware family.
    The 3 export tests fail Red today with `AttributeError: module
    'preflight' has no attribute 'discover'` because the current
    preflight uses a mar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
    [preflight.py]
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2026-05-23 refactor(gantry): rename open_marlin_port -> open_gcode_port (with deprecation alias) (#154)
    * refactor(gantry): rename open_marlin_port -> open_gcode_port (alias deprecated)
    The helper is firmware-agnostic — it's a Linux baud helper with a
    TCSETS2 + BOTHER fallback, nothing Marlin-protocol-specific. The old
    name was misleading.
    - New canonical name: `pipettebot.gantry.open_gcode_port`.
    - Old name `open_marlin_port` preserved for one release cycle as a
    one-line alias that calls `warnings.warn(..., DeprecationWarning,
    stacklevel=2)` then delegates. Removed in 0.2.x.
    TDD:
    - test_open_gcode_port_is_callable — Red (symbol didn't exist), Green
    (function added).
    - test_open_marlin_por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
    [devices.py, diagnose_axis.py, gantry.py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]
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2026-05-24 feat(teleop_lean): sync I/O + env-var smoothing + SIGUSR1 capture (#164)
    * feat(teleop_lean): sync I/O + env-var smoothing + SIGUSR1 capture
    Production-hardens tools/teleop_lean.py for the SO-101 leader -> follower
    teaching workflow after live bring-up on a calibrated dual-arm setup.
    - Replace per-servo read/write with GroupSyncRead/GroupSyncWrite — one
    bus exchange per direction lifts the 15-20 Hz ceiling to 60+ Hz at
    1 Mbaud and removes the visible follower lag that surfaced after
    calibration. Fixes the constructor arg-order trap (port FIRST, then
    packet) that crashed first live runs.
    - Configure follower-side ACC + Goal_Velocity once at startup so the
    receiver ramps locally;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
    [_teleop_common.py, teleop_lean.py, teleop_postprocess.py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]
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2026-09-16 feat(tools/cad/scan): clean and reorient raw pipette 3D scan (#90)
    * feat(tools/cad/scan): clean and reorient raw pipette 3D scan
    Adds a one-shot preprocessor that turns a raw turntable scan of a DLAB
    dPette into an axis-aligned, tip-down reference mesh suitable for
    overlaying against build123d primitives.
    Pipeline (tools/cad/scan/clean_pipette_scan.py):
    - drop disconnected scan-noise components below min-faces threshold
    - PCA on vertices → rotate principal axis to +Z
    - detect tip end by cross-sectional spread, orient tip at z=0 to match
    how the dPette mounts on the i3 carriage
    - PCA on the head section's XY footprint → rotate display-housing long
    axis to +X
    - recenter XY centroid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
    [pipette_scan_raw.stl]
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2026-09-16 feat(bot): add COLUMN_PITCH_MM constant for dPette+ 8-channel (closes #8) (#220)
    Scoped down from the original issue's "8-well column helpers" ask:
    there's no deck/well abstraction in the codebase yet to build real
    column helpers against (deck geometry is deliberately deferred, see
    issue #10), and AGENT_REQUESTS.md no longer has the liquid-handling
    section this issue originally pointed to. Per owner decision, adding
    just the geometry constant now rather than inventing an abstraction
    ahead of the deck library that will actually need it.
    COLUMN_PITCH_MM = 9.0 matches docs/3d-parts.md's already-documented
    SBS row pitch for the dPette+ 8-channel. Docstring notes the physical
    constraint this iss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
    [bot.py]
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2026-09-17 feat: motion-profile kinematics and deck-layout SVG visualization (#224)
    * feat(tools): add motion-profile kinematics + deck-layout SVG visualization
    Closes the quick scope of issue #116. tools/motion_profile_plot.py renders three design-review SVGs to hardware/svg/motion-profile/: kinematics-per-axis (closed-form trapezoidal/triangular velocity profile under the active MotionProfile's M203/M201/M205 caps, jerk modelled as a genuine instantaneous velocity step), a three-view path plot, and a deck-layout top view that replaces the ASCII sketch in docs/sketches/deck-layout-rows-script.md. Deck geometry is read from examples/showcase_v0_i3_full_pipettebot_rows.py via reflection so the plot can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
    [motion_profile_plot.py]
2026-09-17 fix(experiment_profile): extract volume-resolution helpers (closes #223) (#227)
    _resolve_volumes reported cognitive complexity 17, over the
    complexipy gate's max of 15. Split the per_cycle_ul and constant_ul
    branches into their own helper functions; behavior is unchanged
    (existing test suite covers both schema paths).
    [experiment_profile.py]
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
